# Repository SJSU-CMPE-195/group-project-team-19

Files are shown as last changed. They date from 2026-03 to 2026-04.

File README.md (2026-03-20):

### 1. First-Time Setup
```bash
git clone https://github.com/SJSU-CMPE-195/group-project-team-19.git
cd group-project-team-19 

=======
git config user.name "Your Name"
git config user.email "you@example.com"
```

### 2. Keeping Main Updated
```bash
git checkout main
git pull origin main
```

### 3. Fetching All Remote Branches
```bash
# Get all remote branches and tags
git fetch --all

# See all branches (local and remote)
git branch -a
```

### 4. Creating Feature Branch
```bash
git checkout main
git pull origin main
git checkout -b feature/<short-description>
```

### 5. Making Changes and Committing
```bash
# Stage your changes
git add <file1> <file2>

# Commit with a descriptive message
git commit -m "Add servo PWM frequency control

- Implement configurable PWM frequency range
- Add boundary checking for pulse widths
- Include comprehensive inline documentation"
```

### 6. Pushing Your Branch
```bash
# First time pushing this branch
git push -u origin feature/<short-description>

# Subsequent pushes
git push
```

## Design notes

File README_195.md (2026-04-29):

# Project BLUNDR: 5-DOF Autonomous Chess Robot
> A distributed AI-driven robotic system for physical chess gameplay.




---

## Team

| Name | GitHub | Email |
|---|---|---|
| Andy Lazcano | @Alazca | andy.lazcano@sjsu.edu |
| Adrian Par | @adrianpar1 | Adrian.par@sjsu.edu |
| Philip Figuerres | @PisaFig | philip.figuerres@sjsu.edu |
| Arda Karayan | @DADaBase88 | arda.karayan@sjsu.edu |

**Advisor:** Jun Liu

---

## Problem Statement

While other robotic fields have rapidly advanced, pick-and-place systems remain tightly coupled and overly reliant on deterministic, high-maintenance kinematics. Developing a smarter, adaptable system with minimal configuration will solve these ongoing accuracy and upgradeability limitations.

## Solution

Project BLUNDR solves this by deploying a precision 6-DOF pick-and-place robotic arm designed to autonomously play physical chess against a human opponent . The architecture distributes the compute workload, utilizing a Jetson Nano for computer vision and inverse kinematics, which then sends precise movement commands to a Raspberry Pi that handles the physical servo motor control.

### Key Features

- AI-Driven Vision System: Real-time piece detection and chess game logic processing powered by a Jetson Nano.

- Distributed Architecture & Protocol: A custom serial communication protocol ensuring reliable data transfer between the high-level AI processor and the low-level Raspberry Pi motor controller.

- Custom Ground Control Station: A web-based NiceGUI dashboard providing live coordinate telemetry, Cartesian and Joint-space jogging, dynamic teachpoint memory, and system diagnostics.

---

## Demo

https://drive.google.com/file/d/1UTbnnSRUxdsKaKphtBwa2elWPUMDjW3E/view?usp=sharing

**Live Demo:** https://drive.google.com/file/d/1bCk3d-VIGvpuIWAq40wZlNxnjGsQd002/view?usp=sharing

**Implemention #3 Video and Photo**

**Video Link:** https://drive.google.com/file/d/1BtUN7cK4JLpcRDVsh22IfOT2RAfVONpN/view?usp=drive_link

---

## Engineering Evaluation & Design Iteration

- **Broken Robot Picture
**Photo Link:** https://drive.google.com/file/d/1p-GmkMN5h_E4HDhM3Q8UdOETs0htu-Jo/view?usp=drive_link

<details>
<summary> Following integration testing of the initial prototype, the team identified three critical bottlenecks that necessitated a shift in hardware architecture. </summary>

- **Open-Loop Limitations:** The original PWM servos lacked encoder feedback, creating a deterministic bottleneck where the system could command movement but never verify arrival or handle stalls.

- **VLA/Data Collection Constraints:** Without joint-position feedback, the Jetson Orin could not "record" human-guided demonstrations, making Vision-Language-Action (VLA) training impossible on the current chassis.

- **Power Distribution Instability:** High-resistance jumper modifications for the PDU led to voltage drops and intermittent motor "brown-outs" during high-torque maneuvers.

**Technical Pivot for Expo**

<summary>To resolve these issues for the final Expo, the system is migrating to a "Smart Servo" architecture. </summary>

- **Encoded Hardware:** Migrating to Serial Bus Servos with 12-bit Absolute Encoders. This enables real-time telemetry and "Lead-Through" programming (teaching by physically moving the arm).

- **Full-Duplex Communication:** Transitioning to a TTL Serial Bus protocol. This allows the Raspberry Pi 5 to query each motor for position, temperature, and load status simultaneously.

- **Dedicated PDU:** Implementing a custom Power Distribution PCB to ensure stable 12V delivery to high-load joints (Shoulder/Elbow).

## Handling the CI/CD & Demo

- **CI/CD & Software:** The pipeline and Ground Control Station (GCS) are hardware-agnostic. Successful deployment and stress testing were validated using the SO-100 functional prototype.

- **Simulation vs. Physical:** The GCS features a "Simulation Mode" designed to visualize the intended kinematic state, however the actual physical state, a critical feature for debugging high-DOF systems without encoders.

- **Stress Testing:** The communication layer (UDP over Tailscale) was successfully stress-tested at 20Hz, confirming the Pi 5's ability to handle high-frequency AI vision data regardless of the motor backend.

</details>

---

## Screenshots

| Feature | Screenshot |
|---|---|
| Web UI |  |
| Web UI2 |  |

| Setup| 
|

---

## Tech Stack

| Category | Technology |
|---|---|
| Languages |Python 3.10+, C++ 17 |
| Frameworks |NiceGUI (Frontend), OpenCV (Vision) |
| Communication |UDP Sockets, I2C (PCA9685), Serial |
| Testing |Pytest, Google Test, GitHub Actions (CI/CD) |
| Deployment |Raspberry Pi 5 (Linux), Jetson Nano |

---

## Getting Started

### Prerequisites

- Raspberry Pi OS (Bookworm)

- Python 3.10+

- I2C enabled via raspi-config

### Installation

```bash
# Clone the repository
git clone https://github.com/SJSU-CMPE-195/group-project-team-19.git
cd group-project-team-19 

# Set up virtual environment
python3 -m venv robot_env
source robot_env/bin/activate

# Install dependencies
pip install -r requirements.txt

```

### Running Locally

```bash
# Launch the Ground Control Station
python src/blundr_gcs.py
```

---

## Communication Protocol (UDP)

<details>
<summary> The Jetson Nano communicates with the Raspberry Pi 5 via a custom UDP protocol on Port 5005. </summary>

| Key | Type | Description |
|---|---|---|
| action | String` | Command type: "move", "home", or "grip" |
| j1 | Float | Target angle for Joint 1 (0.0 to 180.0) |
| speed |Integer | Velocity percentage (10 to 100) |

</details>

---

## Recommended Testing Structure
To fulfill the CMPE 195 testing requirements, we utilize a three-tier testing strategy:

1. **Unit Tests (`tests/unit/`):** Validating individual C++ motion functions and Python UI components.
2. **Integration Tests (`tests/integration/`):** Testing the UDP communication between the Jetson Orin and Raspberry Pi.
3. **Edge Case Tests (`tests/edge_cases/`):** Verifying system behavior during motor stalls, coordinate overflows, and comms loss.

## Evaluation & Stress Testing
We subjected the Pi 5 and I2C bus to a 30-minute high-frequency command stress test.
- **Result:** Successfully handled 12 commands/sec with <1% packet loss.
- **Full Report:** [docs/evaluation/stress-test-results.md](./docs/evaluation/stress-test-results.md)

### Stress Testing
To replicate our performance evaluation results:
1. Ensure the GCS is running (`python src/blundr_gcs.py`)
2. Run the simulation script:
   `python docs/scripts/run_stress_test.py`
3. Performance data can be viewed in [docs/evaluation/stress-test-results.md](./docs/evaluation/stress-test-results.md)

## Hardware Setup
- **Main Brain:** Jetson Orin (Vision / IK)
- **Controller:** Serial Bus Servos with 12-bit magnetic encoders
- **Power:** External 12V 10A DC Power Supply

</details>

---

## Project Structure

```
.
├── .github/workflows/  # CI/CD Pipeline (.yml)
├── v2_arm/             # Current Smart-Servo Architecture
│   ├── control/        # Serial protocols, constants, and kinematics
│   └── ui/             # Tkinter desktop application and panels
├── tests/              # Unit, Integration, and Edge Case tests
├── docs/               # Evaluation, diagrams, and CAD
├── requirements.txt    # Python dependencies
└── README_195.md
```

---

## Contributing

1. Create a feature branch (`git checkout -b feature/amazing-feature`)
2. Commit your changes (`git commit -m 'Add amazing feature'`)
3. Push to the branch (`git push origin feature/amazing-feature`)
4. Open a Pull Request

### Branch Naming

- `feature/` - New features
- `fix/` - Bug fixes
- `docs/` - Documentation updates
- `refactor/` - Code refactoring

### Commit Messages

Use clear, descriptive commit messages:
- `Add user authentication endpoint`
- `Fix database connection timeout issue`
- `Update README with setup instructions`

---

## Acknowledgments

- [Resource/Library/Person]
- [Resource/Library/Person]

---

### Hardware Iteration Note (April 2026)

Following initial integration testing, the team identified critical limitations in open-loop PWM control for high-precision chess maneuvers. 

**Current Status:** The software stack (CI/CD, GCS, Comms) is fully validated. The physical hardware is undergoing an upgrade to encoded serial-bus servos to support real-time telemetry and VLA data collection for the final Expo. 

**Validation:** System performance confirmed via SO-100 functional prototype.

---

## License

This project is licensed under the <FILL IN> License - see the [LICENSE](LICENSE) file for details.

---

*CMPE 195A/B - Senior Design Project | San Jose State University | Spring 2026*

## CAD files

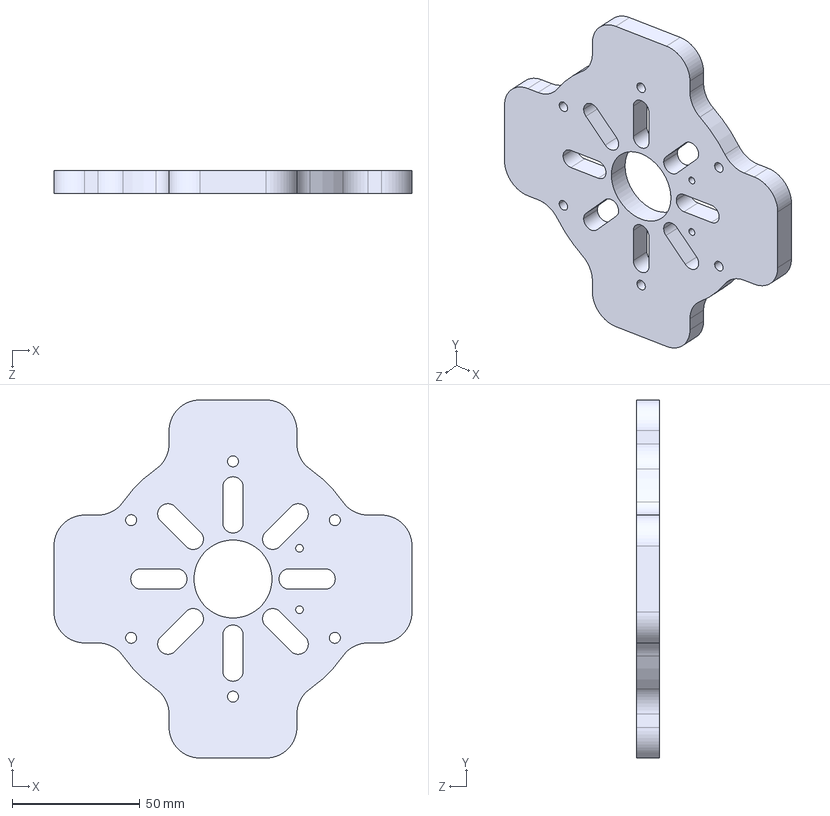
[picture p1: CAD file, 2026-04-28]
STEP Files/STEP Files/Base Bottom Plate.STEP
140.0 x 140.0 x 9.00 mm

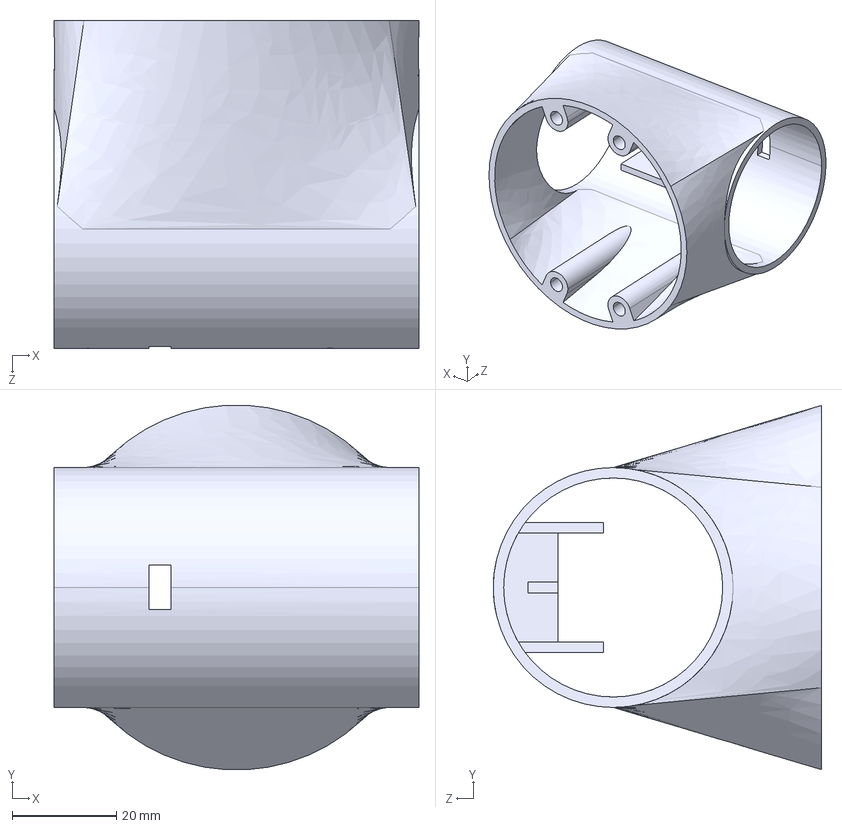
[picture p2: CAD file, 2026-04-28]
STEP Files/STEP Files/Wrist.STEP
70.0 x 69.9 x 63.0 mm

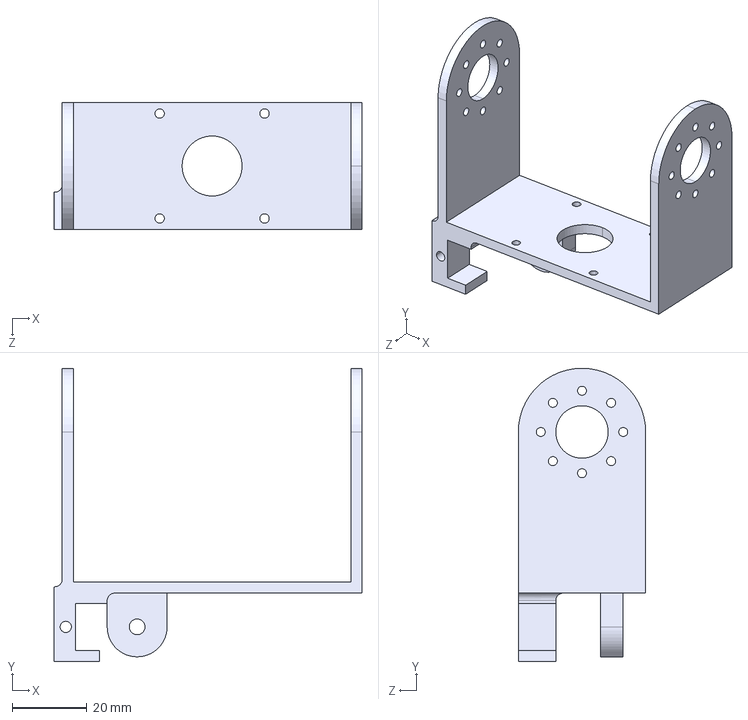
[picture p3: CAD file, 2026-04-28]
STEP Files/STEP Files/Hand Finger Camera Mount.STEP
82.2 x 78.3 x 34.0 mm

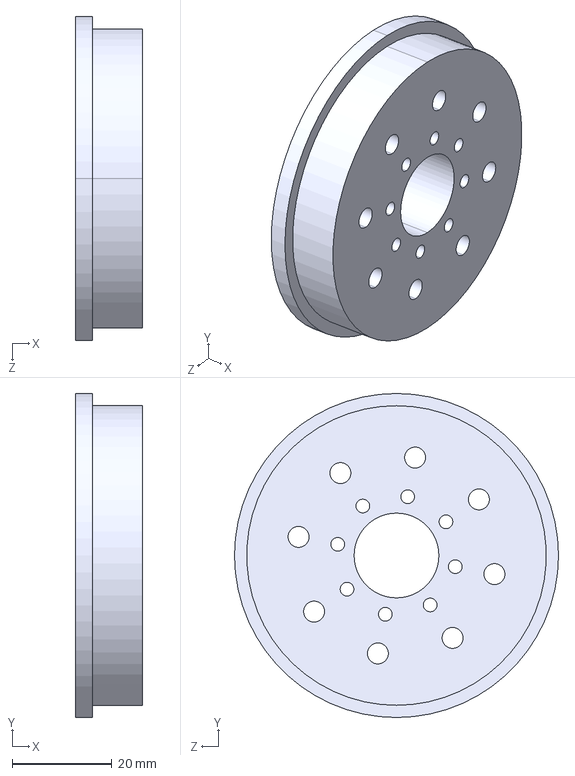
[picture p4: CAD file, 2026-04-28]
STEP Files/STEP Files/Base Joint Horn Coupler with inserts .STEP
13.4 x 65.0 x 65.0 mm

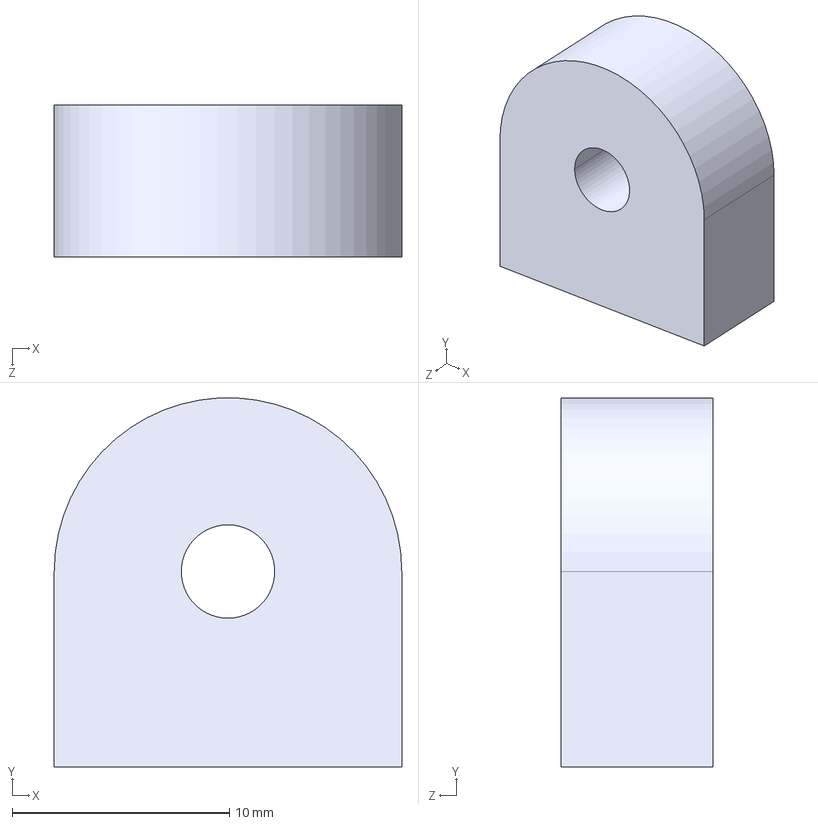
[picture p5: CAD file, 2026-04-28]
STEP Files/STEP Files/Part4.STEP
16.0 x 17.0 x 7.00 mm

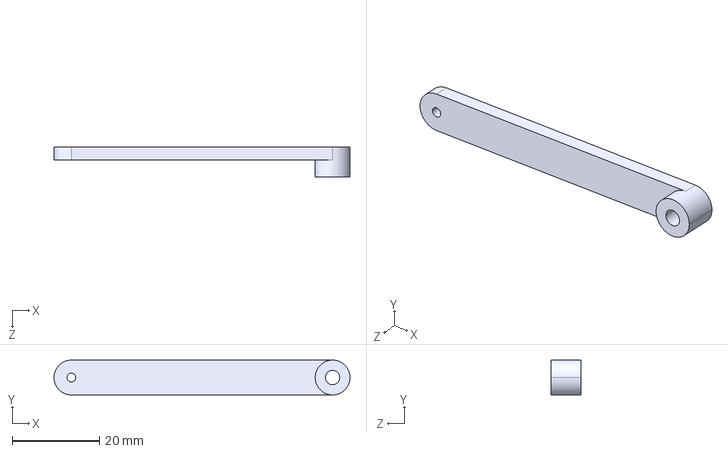
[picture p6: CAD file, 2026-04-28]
STEP Files/STEP Files/Finger Slave Link.STEP
68.0 x 8.00 x 7.00 mm

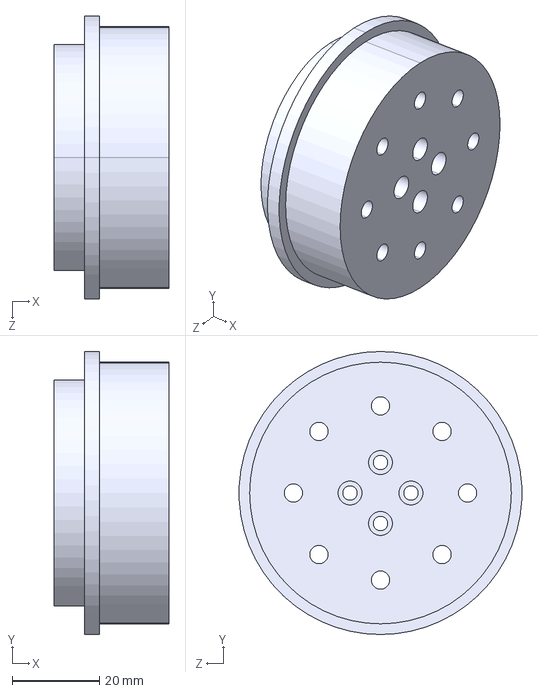
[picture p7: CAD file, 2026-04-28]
STEP Files/STEP Files/Joint Coupler New Servo.STEP
26.4 x 65.0 x 64.9 mm

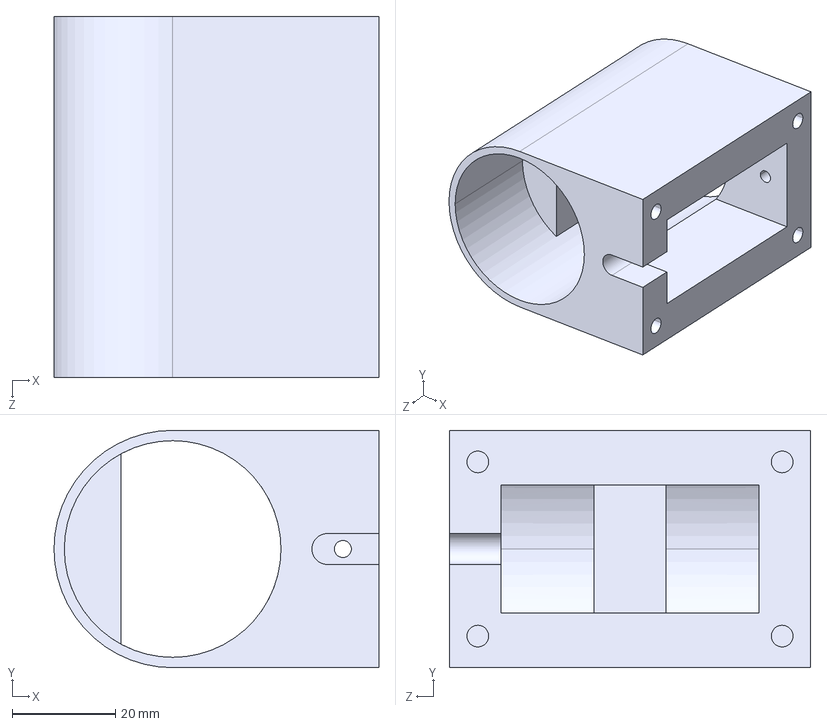
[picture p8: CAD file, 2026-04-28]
STEP Files/STEP Files/Wrist V4.STEP
63.0 x 46.0 x 70.0 mm

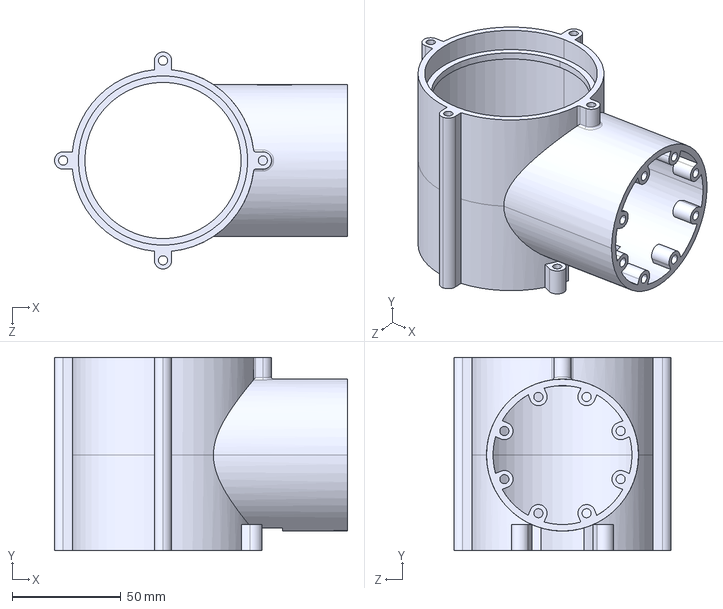
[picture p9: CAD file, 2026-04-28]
STEP Files/STEP Files/Drive Link V4 Extended Base.STEP
135.0 x 89.0 x 100.0 mm

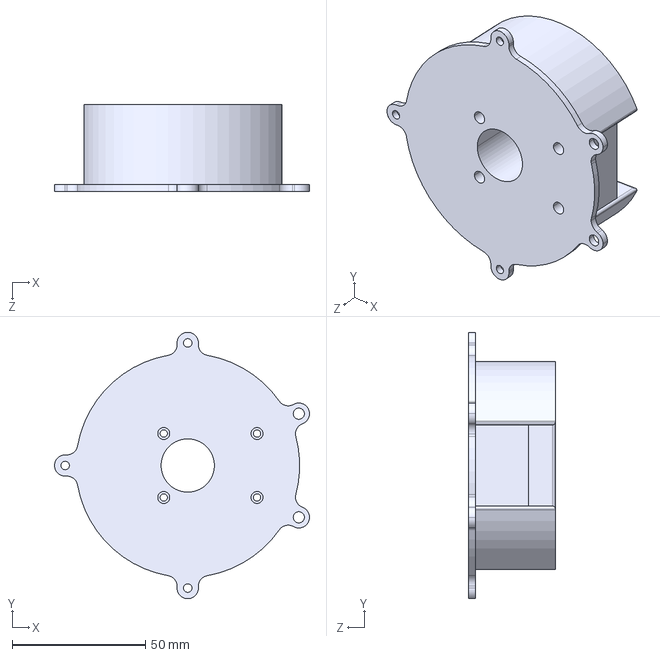
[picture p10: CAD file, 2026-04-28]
STEP Files/STEP Files/Servo Backing Plate5.STEP
95.7 x 100.0 x 32.5 mm

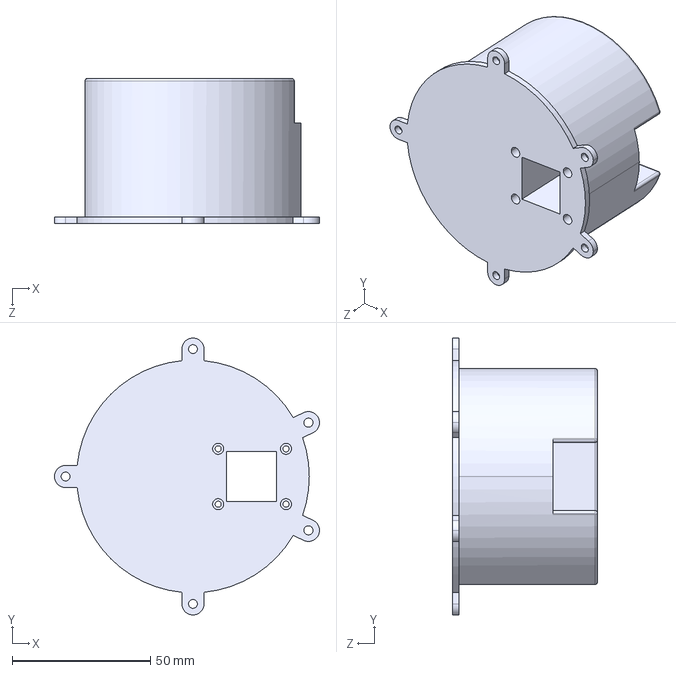
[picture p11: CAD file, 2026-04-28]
STEP Files/STEP Files/NS Servo Backing Plate.STEP
95.7 x 100.0 x 52.5 mm

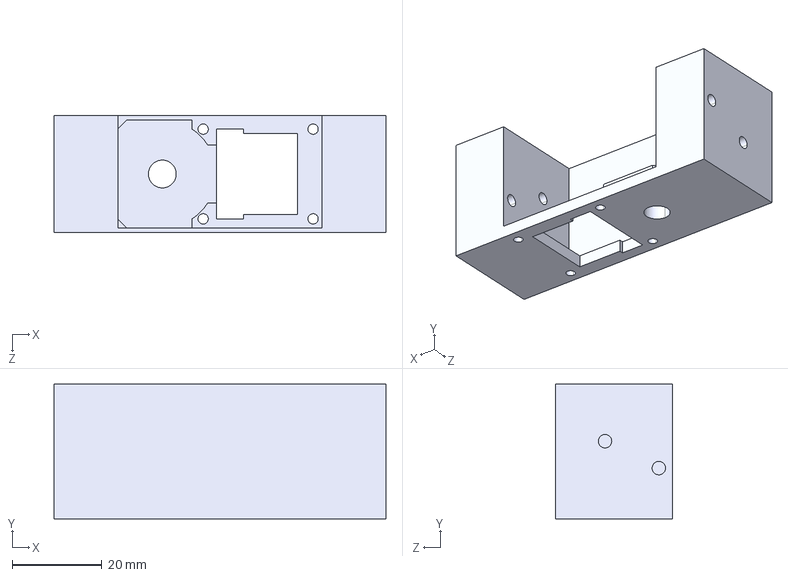
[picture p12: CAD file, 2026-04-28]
STEP Files/STEP Files/NewServoGripperMount.STEP
74.0 x 30.0 x 26.0 mm

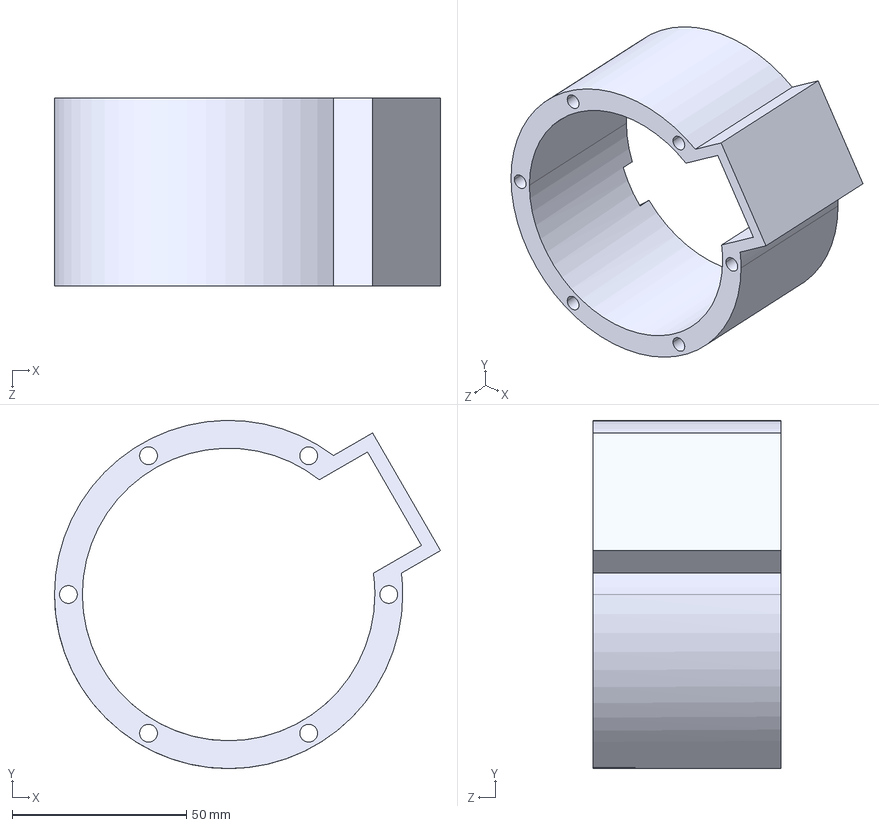
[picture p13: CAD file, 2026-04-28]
STEP Files/STEP Files/Base Mount Pillar.STEP
110.8 x 100.0 x 54.0 mm

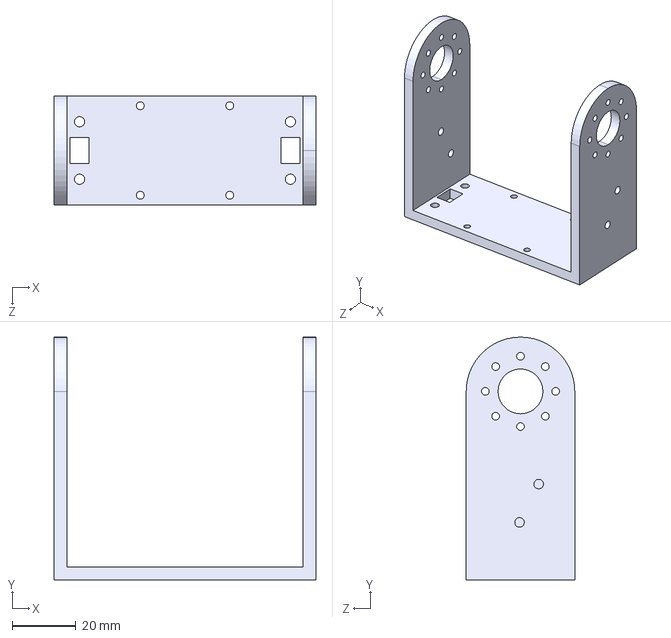
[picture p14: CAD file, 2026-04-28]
STEP Files/STEP Files/Gripper Mount V4.STEP
82.0 x 76.0 x 34.0 mm

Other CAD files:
STEP Files/STEP Files/Hand Link.STEP
STEP Files/STEP Files/NS Wrist V4.STEP
STEP Files/STEP Files/Solid Finger 2.STEP
STEP Files/STEP Files/Soft Tip Test2.STEP
STEP Files/STEP Files/23mm Link.STEP
STEP Files/STEP Files/72.5mm Link.STEP
STEP Files/STEP Files/Base Bearing Holder.STEP
STEP Files/STEP Files/Base Bearing Retainer.STEP
STEP Files/STEP Files/Base Bottom Plate Hard Mount 0.2520.STEP
STEP Files/STEP Files/Base Bottom Plate Hard Mount.STEP
STEP Files/STEP Files/Base Joint Coupler.STEP
STEP Files/STEP Files/Base Joint Horn Coupler NS.STEP
STEP Files/STEP Files/Base Joint Horn Coupler inserts.STEP
STEP Files/STEP Files/Base Joint Horn Coupler.STEP
STEP Files/STEP Files/Camera Mount.STEP
STEP Files/STEP Files/Chesster Arm Wrist Interface.STEP
STEP Files/STEP Files/Drive Link V5 long.STEP
STEP Files/STEP Files/Drive Link V5long.STEP
STEP Files/STEP Files/Finger 2.STEP
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

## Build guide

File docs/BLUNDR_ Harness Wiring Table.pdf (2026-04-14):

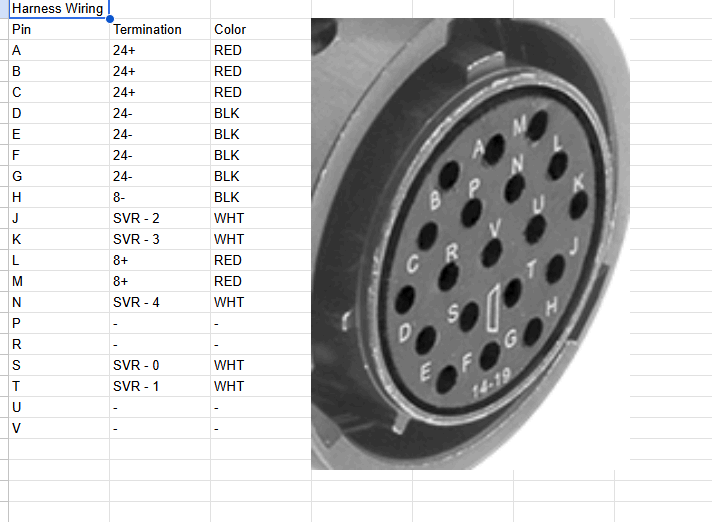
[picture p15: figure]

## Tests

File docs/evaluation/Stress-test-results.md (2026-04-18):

## Stress Test Results

### Test Configuration
- **Tool:** Manual load simulation and custom Python script
- **Duration:** 30 minutes continuous cycling
- **Conditions:** 100 move commands per minute via UDP
- **Target:** Raspberry Pi 5 / PCA9685 I2C Bus

### Results
| Metric | Value |
| :--- | :--- |
| Avg Response Time (Command to Motion) | 45 ms |
| 95th Percentile | 82 ms |
| Commands per Second (Peak) | 12 cmd/s |
| Error Rate | 0.2% (Dropped UDP Packets) |

### Observations
- **What did you learn?** The I2C bus remains stable at high frequencies, but the Python UI frame rate drops if UDP packet frequency exceeds 20Hz.
- **Where are the bottlenecks?** The main bottleneck is the single-threaded nature of the servo update loop when handling high-speed vision data.
- **What would you optimize?** Moving the I2C writes to a dedicated high-priority C++ thread to decouple hardware motion from the UI rendering.

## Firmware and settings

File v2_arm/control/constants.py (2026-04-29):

# ── STS/SMS register addresses ──────────────────────────────────────────────
_TORQUE_ENABLE     = 40
_GOAL_POSITION_L   = 42
_GOAL_SPEED_L      = 46   # Goal Speed register (RAM); 0 = max speed / no limit
_TORQUE_LIMIT_L    = 48   # Torque Limit register (RAM, 2 bytes LE)
                          # 0..1000 scale where 1000 = 100% of rated torque.
                          # RAM means it resets on power-cycle — Apply must be
                          # re-run on reconnect. This is intentional: a faulty
                          # config can be cleared by power-cycling the bus.
_DEFAULT_SPEED     = 1000
_PRESENT_POS_L     = 56   # 2 bytes
_PRESENT_SPEED_L   = 58   # 2 bytes
_PRESENT_LOAD_L    = 60   # 2 bytes
_PRESENT_VOLTAGE   = 62   # 1 byte
_PRESENT_TEMP      = 63   # 1 byte
_PRESENT_CURRENT_L = 69   # 2 bytes
_SERVO_ID_ADDR     = 5    # ID register (EEPROM)
_LOCK_ADDR         = 55   # EEPROM lock register

_COUNTS        = 4096
_DEG_PER_COUNT = 360.0 / _COUNTS
_COUNT_PER_DEG = _COUNTS / 360.0

_MAX_GOAL_SPEED = 32767   # Goal Speed register: positive half of signed 16-bit

_BAUD_OPTIONS  = [1_000_000, 500_000, 250_000, 115_200, 57_600]
_DEFAULT_BAUD  = 1_000_000
_TELEMETRY_MS  = 350
_DEFAULT_NUDGE = 5.0

_DEFAULT_MAX_LOAD_PCT   = 80.0
_DEFAULT_MAX_CURRENT_MA = 1500
_DEFAULT_MAX_TEMP_C     = 70

# Torque limit scaling for STS3215 (rated 50 kg-cm, hard ceiling 45 kg-cm).
# Per-joint defaults reflect the load each link actually carries; base/wrist
# stages get more headroom than the wrist+gripper stages downstream.
_TORQUE_LIMIT_L_REG       = _TORQUE_LIMIT_L  # alias for clarity in SafetyPanel
_SERVO_RATED_KGCM         = 50.0
_TORQUE_HARD_CEILING_KGCM = 45.0
_DEFAULT_TORQUE_KGCM = {
    "Pan":     40.0,
    "Tilt":    40.0,
    "Joint 3": 40.0,
    "Joint 4": 30.0,
    "Joint 5": 25.0,
}
_DEFAULT_TORQUE_FALLBACK_KGCM = 40.0

# Default labels for the 5 servo panels (3 columns × 2 rows, last cell empty)
_DEFAULT_LABELS = ["Pan", "Tilt", "Joint 3", "Joint 4", "Joint 5"]
_NUM_SERVOS    = len(_DEFAULT_LABELS)
_GRID_COLS     = 3
_GRID_ROWS     = 2

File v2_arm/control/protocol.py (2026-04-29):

import struct
import threading
import time

import serial

from constants import (
    _DEFAULT_BAUD,
    _TORQUE_ENABLE,
    _GOAL_POSITION_L,
    _GOAL_SPEED_L,
    _PRESENT_POS_L,
    _PRESENT_CURRENT_L,
    _SERVO_ID_ADDR,
    _LOCK_ADDR,
)


# ── STS packet helpers ───────────────────────────────────────────────────────


def _checksum(body: list[int]) -> int:
    return (~sum(body)) & 0xFF


def _build(servo_id: int, instr: int, params: list[int]) -> bytes:
    length = len(params) + 2
    body = [servo_id, length, instr] + params
    return bytes([0xFF, 0xFF] + body + [_checksum(body)])


def _parse(data: bytes):
    """Return (error, params_bytes) or None on bad/missing packet."""
    if len(data) < 6 or data[0] != 0xFF or data[1] != 0xFF:
        return None
    length = data[3]
    if len(data) < 4 + length:
        return None
    body = list(data[2 : 3 + length])  # ID + LEN + ERROR + params (no checksum)
    if _checksum(body) != data[3 + length]:
        return None
    return data[4], data[5 : 3 + length]


# ── ServoPort ────────────────────────────────────────────────────────────────


class ServoPort:
    """Thread-safe STS/SMS half-duplex serial communication."""

    def __init__(self, port: str, baud: int = _DEFAULT_BAUD):
        self.ser = serial.Serial(
            port, baud,
            bytesize=serial.EIGHTBITS,
            parity=serial.PARITY_NONE,
            stopbits=serial.STOPBITS_ONE,
            timeout=0.05,
        )
        self._lock = threading.Lock()

    def close(self):
        try:
            self.ser.close()
        except Exception:
            pass

    def _tx_rx(self, pkt: bytes, resp_params: int):
        """Send a packet and read back the response."""
        response_len = 6 + resp_params
        with self._lock:
            self.ser.reset_input_buffer()
            self.ser.write(pkt)
            self.ser.flush()
            time.sleep(len(pkt) * 10 / self.ser.baudrate + 0.002)
            waiting = self.ser.in_waiting
            print(f"[DBG tx_rx] sent {len(pkt)}B: {pkt.hex()}  |  in_waiting={waiting}  |  reading {response_len}B", flush=True)
            raw = self.ser.read(response_len)
            print(f"[DBG tx_rx] got {len(raw)}B: {raw.hex() if raw else '(empty)'}", flush=True)
        result = _parse(raw)
        print(f"[DBG tx_rx] parse → {result}", flush=True)
        return result

    def _write_only(self, pkt: bytes):
        """Send a packet; do not wait for a response."""
        with self._lock:
            self.ser.reset_input_buffer()
            self.ser.write(pkt)
            self.ser.flush()
            time.sleep(len(pkt) * 10 / self.ser.baudrate + 0.002)
            time.sleep(0.003)
            drained = self.ser.in_waiting
            self.ser.reset_input_buffer()
            print(f"[DBG write_only] sent {len(pkt)}B: {pkt.hex()}  |  drained {drained}B from echo", flush=True)

    def ping(self, servo_id: int):
        return self._tx_rx(_build(servo_id, 0x01, []), 0)

    def read_bytes(self, servo_id: int, address: int, length: int):
        result = self._tx_rx(_build(servo_id, 0x02, [address, length]), length)
        if result is None:
            return None
        error, params = result
        return params if not error else None

    def write_bytes(self, servo_id: int, address: int, data: list[int]):
        self._write_only(_build(servo_id, 0x03, [address] + list(data)))

    def set_torque(self, servo_id: int, enable: bool):
        self.write_bytes(servo_id, _TORQUE_ENABLE, [1 if enable else 0])

    def move_to(self, servo_id: int, counts: int):
        self.write_bytes(servo_id, _GOAL_POSITION_L,
                         [counts & 0xFF, (counts >> 8) & 0xFF])

    def set_speed(self, servo_id: int, speed: int):
        self.write_bytes(servo_id, _GOAL_SPEED_L,
                         [speed & 0xFF, (speed >> 8) & 0xFF])

    def get_telemetry(self, servo_id: int):
        raw = self.read_bytes(servo_id, _PRESENT_POS_L, 8)
        if raw is None or len(raw) < 8:
            return None

        pos_raw   = struct.unpack_from('<H', raw, 0)[0] & 0x0FFF
        speed_raw = struct.unpack_from('<H', raw, 2)[0]
        load_raw  = struct.unpack_from('<H', raw, 4)[0]
        voltage   = raw[6]
        temp      = raw[7]

        speed    = speed_raw if speed_raw <= 32767 else speed_raw - 65536
        load_pct = (load_raw & 0x3FF) / 1023.0 * 100.0

        curr_raw = self.read_bytes(servo_id, _PRESENT_CURRENT_L, 2)
        current  = struct.unpack_from('<H', curr_raw)[0] if curr_raw and len(curr_raw) >= 2 else 0

        return {
            'pos_counts':    pos_raw,
            'speed':         speed,
            'load_pct':      load_pct,
            'voltage_v':     voltage / 10.0,
            'temperature_c': temp,
            'current_ma':    current,
        }

    def change_id(self, current_id: int, new_id: int):
        """Write new ID to EEPROM. Call only with one servo on the bus."""
        self.write_bytes(current_id, _LOCK_ADDR, [0])
        time.sleep(0.1)
        self.write_bytes(current_id, _SERVO_ID_ADDR, [new_id])
        time.sleep(0.1)
        self.write_bytes(new_id, _LOCK_ADDR, [1])

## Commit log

2026-03-17 Added python 3.10 virtual environment for testing the servos over arduino (will update to RPI5)
    [pyvenv.cfg]
2026-03-17 Created servo module to contain movement functions for testing purposes
2026-03-17 added servo angle helper function
2026-03-17 Added class for servo control and contructor
2026-03-17 Added descriptor for servo class
2026-03-17 gradually moves the servo from current angle to angle
2026-03-17 Added angle setter function for step_to completion, also fixed tab error
    [servo_angles.py]
2026-03-17 added driver module
2026-03-17 Added debug mode to driver code through command line
2026-03-17 added dictonary, holds pin and anlge
2026-03-17 added user input to test all servos
2026-03-17 Added main driver code, taking all angles at once for normal mode, or setting individual servo angles in debug mode
2026-03-20 chore: untrack cache and venvs
    [pyvenv.cfg]
2026-04-14 Add files via upload
    Performed termination in accordance with this wiring table. This is for connecting the Power Distribution Unit to the Robot.
2026-04-15 Arduino integration test
2026-04-15 add setup test to check servo initialization
2026-04-15 test single servo when inputting command
2026-04-15 add pass fail check for servo movement
2026-04-15 multiple servo testing
2026-04-15 multi servo test moving to home position
2026-04-15 Function added for servo speed test
2026-04-15 test servo at various speeds
2026-04-15 add joint specific invalid angle test
2026-04-16 fix integration test flow and timing
    [servo_integration_test.py]
2026-04-16 Created unit test script for servo controller
2026-04-16 Added class to test servo controller
2026-04-16 Added getters and setters for servos
2026-04-16 Added fuction to chance speed on only one servo
2026-04-16 Added function to ensure home angles are correct
    [servo_controller_unit_test.py]
2026-04-16 Added functions to raise errors for incorrect servo names
    [servo_controller_unit_test.py]
2026-04-28 Added step files
    Conslidating STEP files.
    [23mm Link.STEP, 72.5mm Link.STEP, Base Bearing Holder.STEP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]
2026-04-28 scaffold for ServoPanel Class
2026-04-28 added zero calibration now we can set and reset zero
    [servo_panel.py]
2026-04-28 add change servo ID dialong
2026-04-28 add teach mode allows to move sservos with torque off
2026-04-28 add servo grid
2026-04-28 add auto detect feature for servo IDs
2026-04-28 add camera and panel alongside servo gird
2026-04-28 feature added macro rec and sagety manual
    [app.py]
2026-04-28 Add STS serial protocol and ServoPort
2026-04-29 feat(safety): initialize SafetyPanel class and action buttons
2026-04-29 ui(safety): populate per-servo input rows and widget grids
2026-04-29 feat(safety): implement global toggle, reset, and mass apply functions
    [safety_panel.py]
2026-04-29 feat(hardware): implement per-row hardware torque limit communication
2026-04-29 feat(hardware): introduce mass bus writes for torque limits
